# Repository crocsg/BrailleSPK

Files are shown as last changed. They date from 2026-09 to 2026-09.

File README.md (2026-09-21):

# BrailleSPK
 
 BrailleSPK is an experimental small device where you can enter a Braille character on a 6 dots permanent keyboard and use action switches to start some action. At the moment, when you used the first action switch, BrailleSPK will announce on audio the meaning of the Braille combination entered on the 6 dots Braille keyboard. All dots and switch are designed to be tactile so you can easily feel if one dots is pressed or not on the Braille keyboard, and you can also feel a little 'click' when you use the action switch. The 6 dots matrix keyboard is designed in such a way you can clearly feel if the button is up or down, so you can easily feel the Braille combination with a finger. At the end, the device frame, Braille dots and tactile switch  are 3d printed parts.

 The device is based on a 6 dots Braille permanent keyboard, 3 action switches, a Seeed Studio  XIAO ESP32C3, an I2S audio amp and a speaker. 

*An image of a fully assembled BrailleSPK*

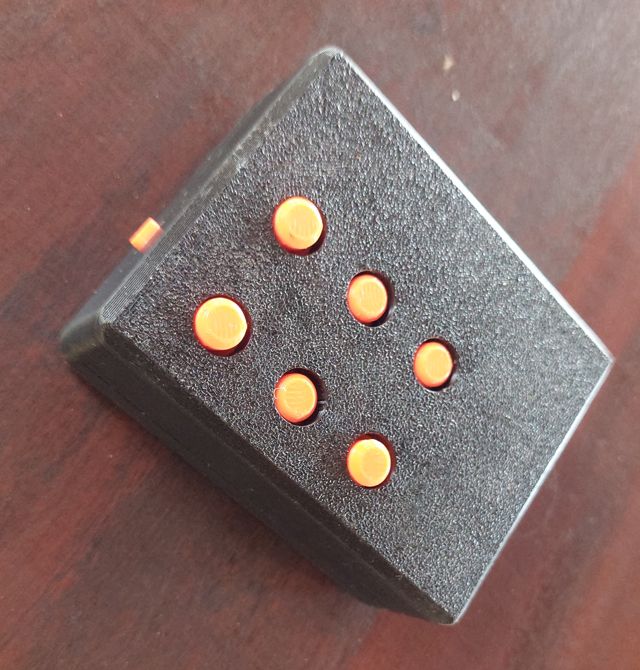
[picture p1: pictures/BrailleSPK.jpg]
An image of BrailleSPK device fully assembled with 6 large orange buttons for Braille, and a small orange tactile action switch


 ## Datasheet

 - a matrix keyboard with 2 columns and 4 rows. The Braille Keyboard use 2x3 switches position with lock/unlock switches. There is also 2 temporary switches on the 4th row we can use as temporary tactile switch.
 - 1 temporary switch connected to a GPIO, so it's suitable for interruption handling.
 - a Seeed Studio XIAO ESP32C3 (1 CPU, 4 Mo flash, 520 Mo RAM and Li-ION battery charge circuit)
 - an Adafruit MAX98357A I2S amplifier or compatible.
 - a 1510 cavitation speaker 

## BOM
  The Bill Of Material is available in [bom.md](bom.md)

## Building manual
  The assembly manual is available in [building.md](building.md)

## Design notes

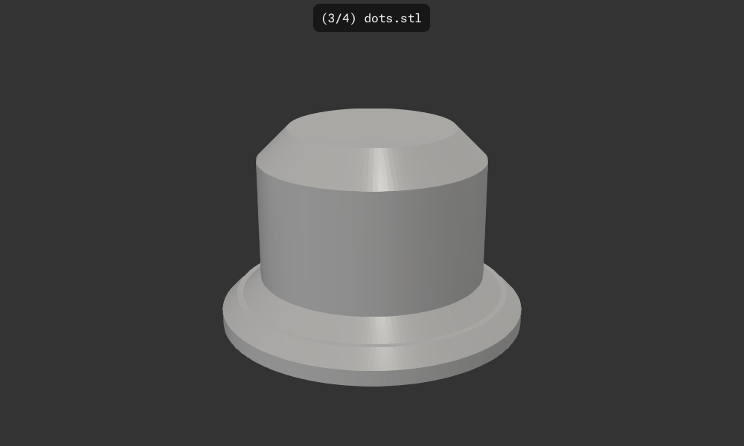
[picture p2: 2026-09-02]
pictures/dots_1.png

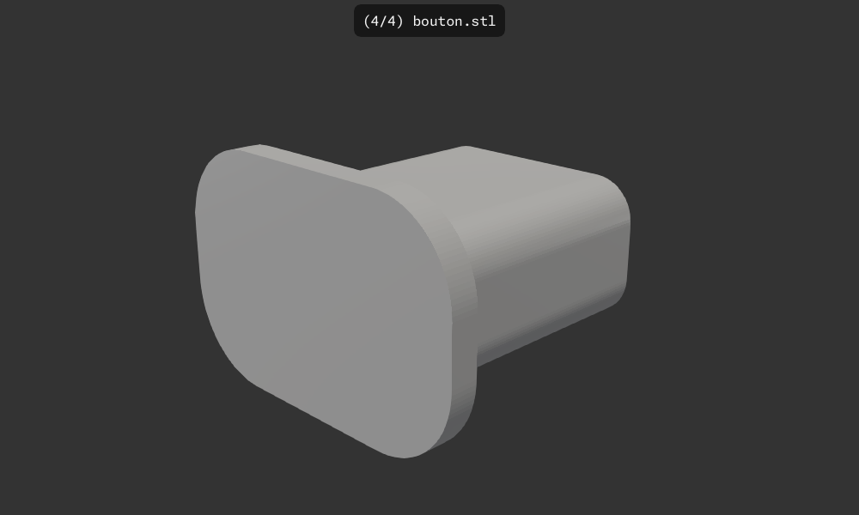
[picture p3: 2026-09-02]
pictures/bouton_1.png

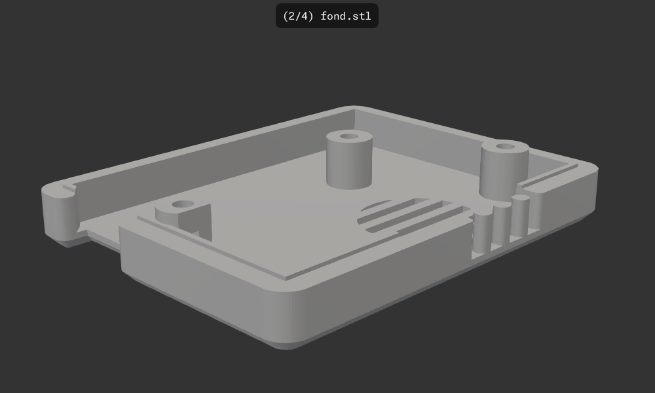
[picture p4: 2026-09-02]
pictures/fond_2.png

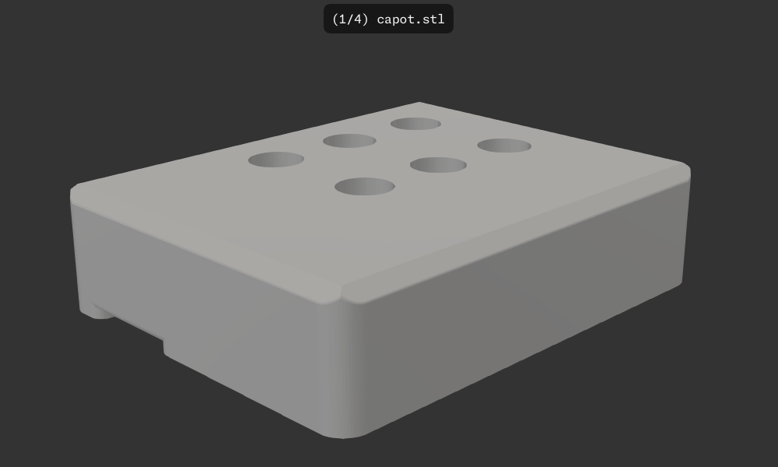
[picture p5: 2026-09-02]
pictures/capot_1.png

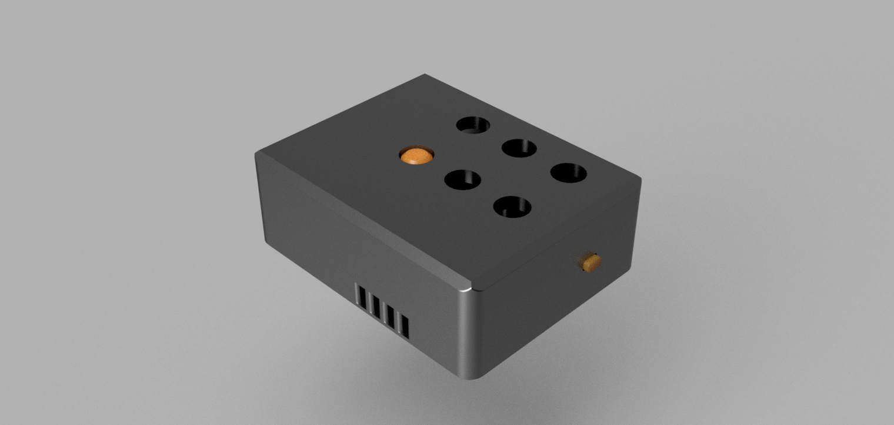
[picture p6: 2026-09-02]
pictures/BrailleSPKv2.png

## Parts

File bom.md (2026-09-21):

# BrailleSPK BOM

## 3D printed parts

 - 1 [capot.stl](3dprint\capot.stl) 
 - 1 [fond.stl](3dprint\fond.stl)
 - 1 [bouton.stl](3dprint\bouton.sl)
 - 6 [dots.stl](3dprint\dots.stl)

#### Printed parts details

  capot.stl
  Capot.stl

  fond.stl
  fond.stl

  bouton.stl
  bouton.stl

  dots.stl
  dots.stl

  These 3d views of printed part where generated with [F3D](https://f3d.app/) a great open source tool to display or render 3d files.

## Electronics

 - 1 BrailleSPK pcb (link coming soon)
 - 1 [Seeed Studio XIA ESP32-C3](https://wiki.seeedstudio.com/XIAO_ESP32C3_Getting_Started/).
 - 1 [Adafruit compatible I2S audio amp(MAX98357A)](https://www.adafruit.com/product/3006?srsltid=AU7gw4UqV06eJcSOT4ILpHE0YxdvCbpwST3pz8Ttz9znPxJfweLLO32w).
 - 1 [1510 Smartphone speaker](https://fr.aliexpress.com/item/1005009800665960.html).
 - 1 2.54 males headers pin (2 x 7pins for XIAO, 1 x 7pins for amp, 2 x 1pin for audio output).

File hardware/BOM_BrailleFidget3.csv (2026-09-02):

ID | Name | Designator | Footprint | Quantity | Manufacturer Part | Manufacturer | Supplier | Supplier Part | Price
1 | XIAO ESP32C3 | U9 | CONN-SMD_XIAO_ESP32C3 | 1 | XIAO ESP32C3 | null | LCSC | C19189385
2 | MAX98357A_KP | U7 | MAX98357A | 1 |  |  | ebay
3 | 1N4148WT_C970342 | D1,D2,D3,D4,D5,D6,D7,D8 | SOD-523F_L1.2-W0.8-LS1.7-RD | 8 | 1N4148WT | LGE(鲁光) | LCSC | C970342 | 0.013
4 | HDR-M-2.54_1x2 | J1 | HDR-M-2.54_1X2 | 1 |  |  | LCSC | C124375 | 0.03
5 | TS24CA 250GF 013 | SW1,SW2,SW3 | SW-SMD_L4.7-W3.5-P3.35-EH | 3 | TS24CA 250gf 013 | SHOU HAN(首韩) | LCSC | C5373430 | 0.026
6 | PS-7054DVB-6PL-REG | U1,U2,U3,U4,U5,U6 | SW-TH_6P-L7.0-W7.0-P2.00-REG. | 6 | PS-7054DVB-6PL | G-Switch(品赞) | LCSC | C22363819 | 0.176
7 | 100kΩ | U8 | R0402 | 1 | FRC0402J104 TS | FOJAN(富捷) | LCSC | C2906883 | 0.002

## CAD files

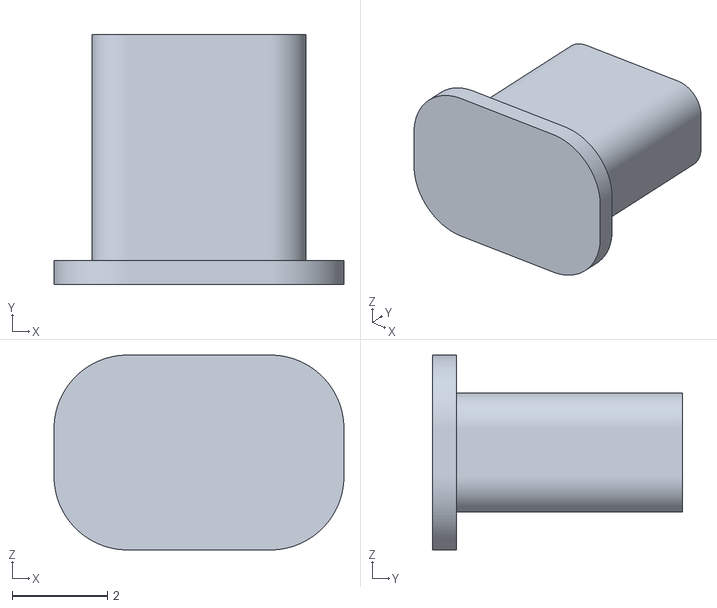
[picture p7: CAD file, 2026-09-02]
3dprint/bouton.stl
6.10 x 5.25 x 4.10

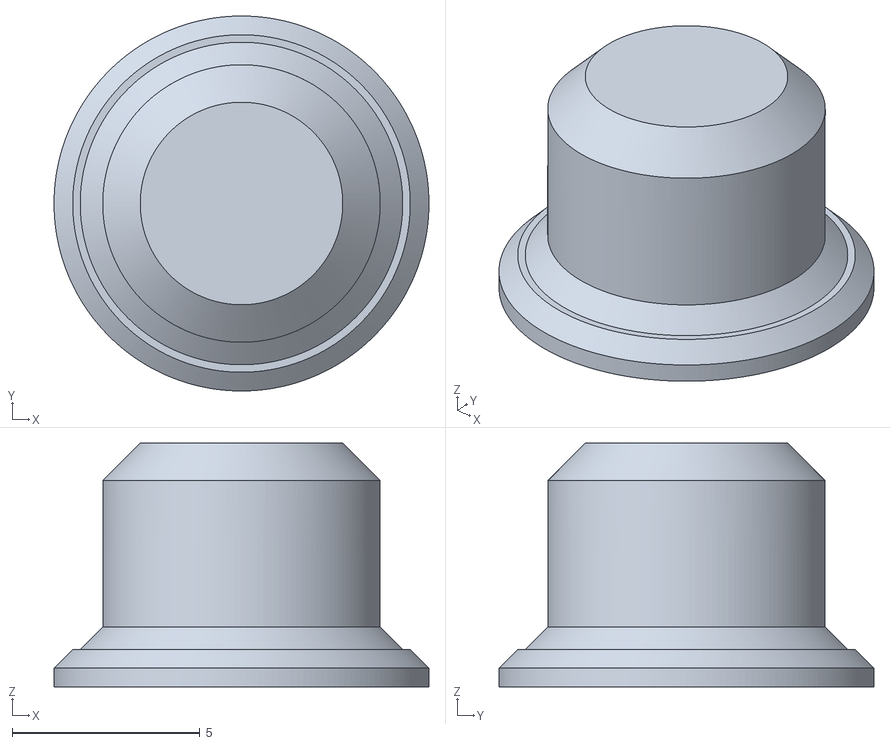
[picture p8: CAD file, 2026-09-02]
3dprint/dots.stl
10.0 x 10.00 x 6.50

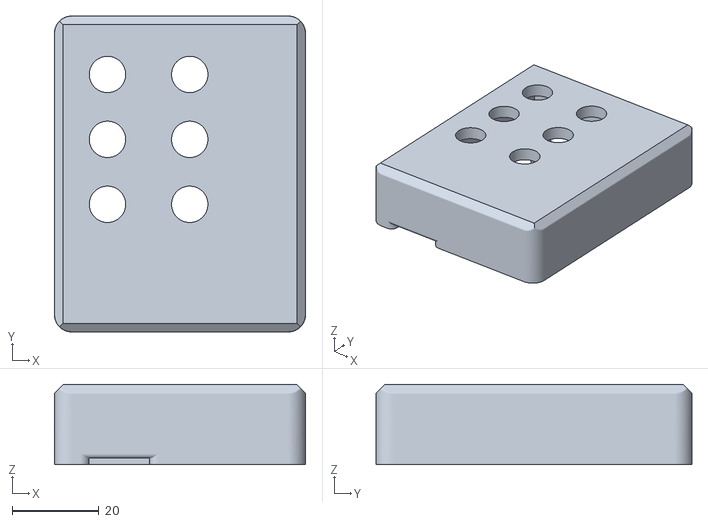
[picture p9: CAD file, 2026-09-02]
3dprint/capot.stl
58.0 x 73.0 x 18.5

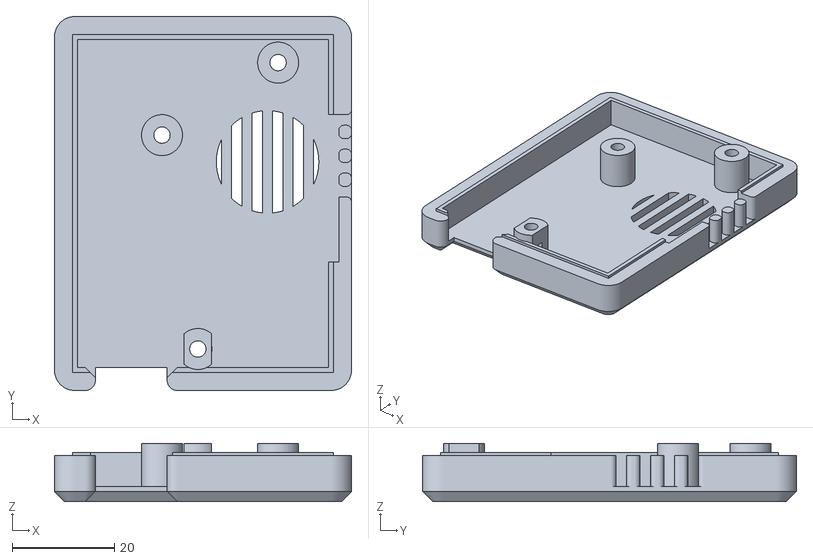
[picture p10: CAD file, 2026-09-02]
3dprint/fond.stl
58.0 x 73.0 x 11.4

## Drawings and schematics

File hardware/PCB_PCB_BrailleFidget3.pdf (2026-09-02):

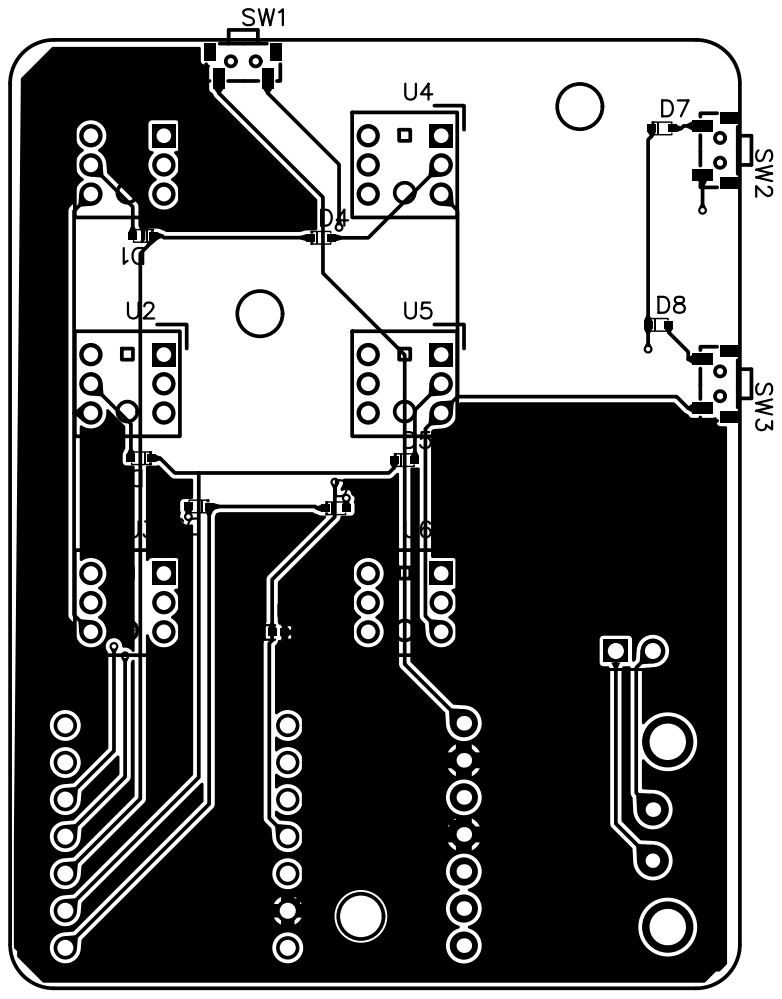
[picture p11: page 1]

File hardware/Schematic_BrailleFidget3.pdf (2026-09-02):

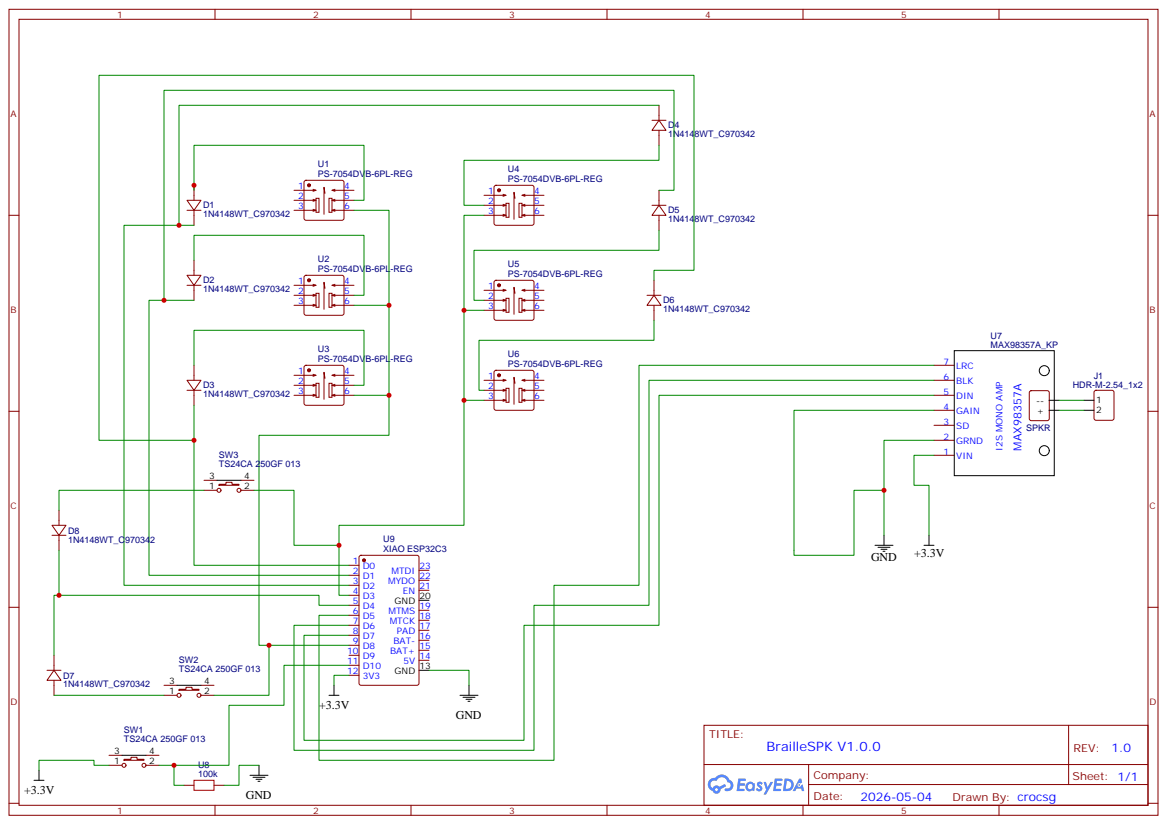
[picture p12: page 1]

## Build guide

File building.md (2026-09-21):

# BrailleSPK building manual

## Solder elements on PCB

### XIAO ESP32-C3 Welding

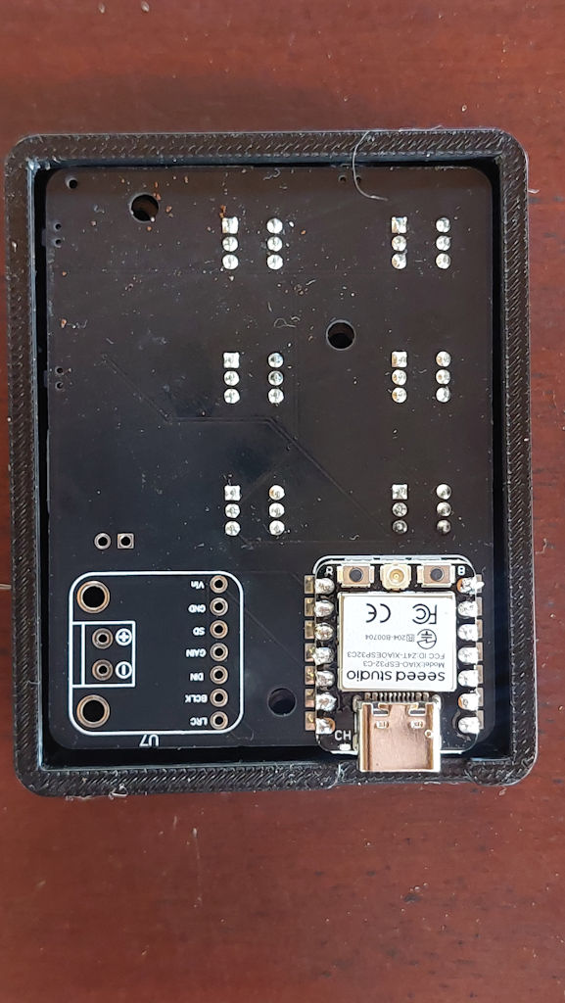
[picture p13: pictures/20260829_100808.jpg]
The ESP32C3 in place


 - Take care of the USB connector orientation to place the MCU on board

### Audio Amp Welding

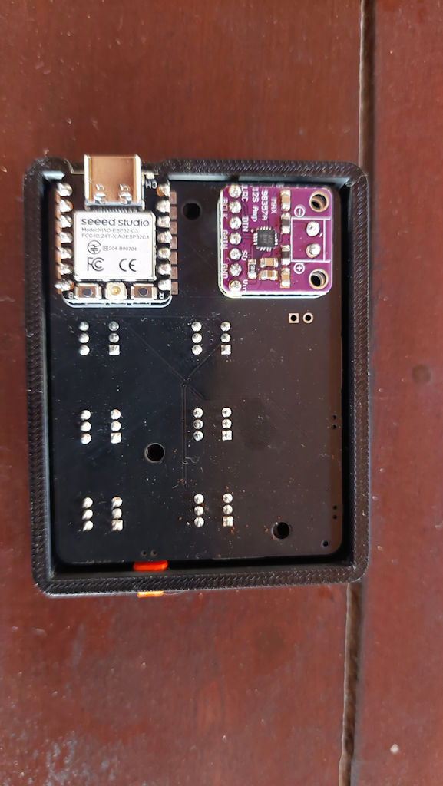
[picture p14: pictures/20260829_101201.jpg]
The audio amp in place


 - We use header pin to solder the audio output on the PCB. On audio amp the output connector use 3mm space. I've used 2 isolated pins cut from a standard 2.54 header.

### Soldering the speaker and glue it on PCB

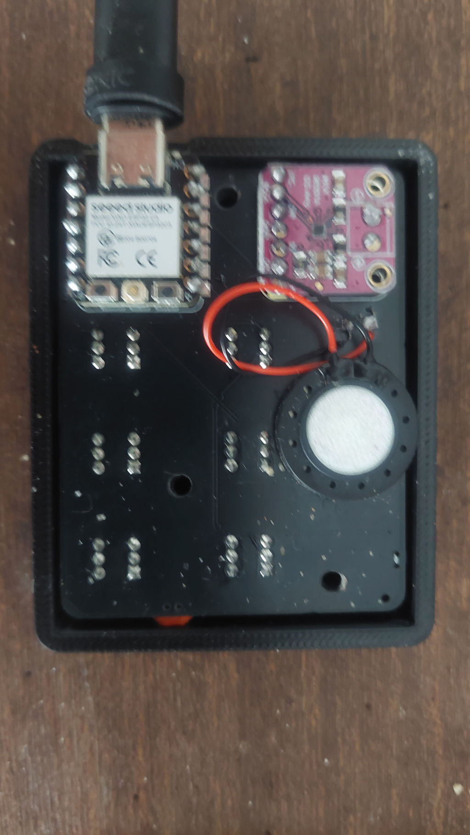
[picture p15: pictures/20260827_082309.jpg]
The audio speaker in place


- Solder the speaker wire on the BrailleSPK PCB. Respect the +/- polarity of the speaker.
- Glue the speaker on the PCB. Most 1510 speaker are equipped with adhesive tape.

### Upload the firmware

 - Open the firmware in 'firmware' directory with Arduino IDE version 2.3.x or later
 - Install ESP32 compiler if needed ([detail instructions available here](https://wiki.seeedstudio.com/Getting_Started_with_Arduino/))
 - Select **XIAO ESP32-C3** in menu **Tools/Board**.

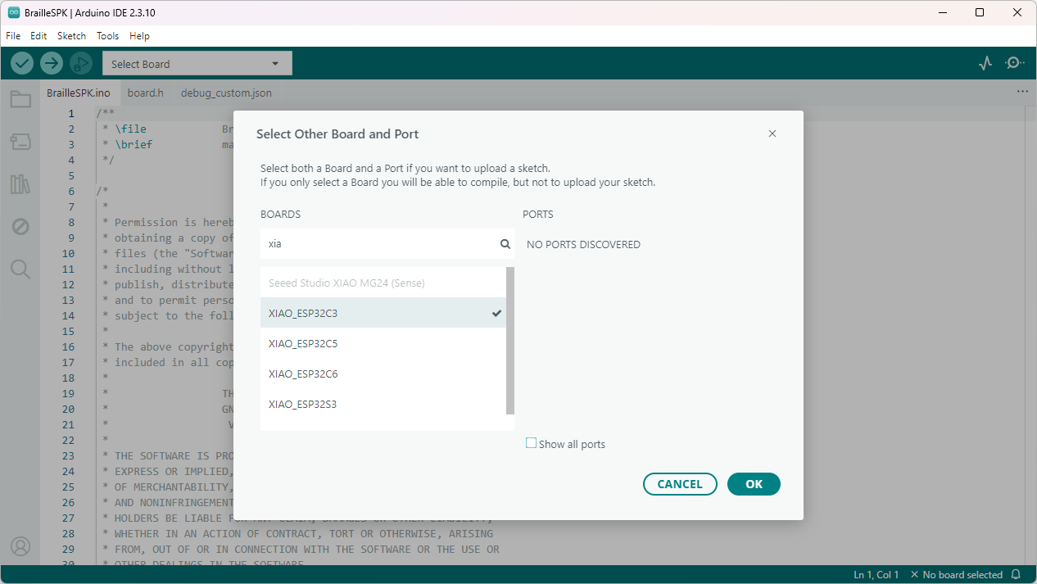
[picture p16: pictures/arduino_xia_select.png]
Select XIAO
 
 
 - Select "Huge partition scheme" in menu **Tools/Partition Scheme**.

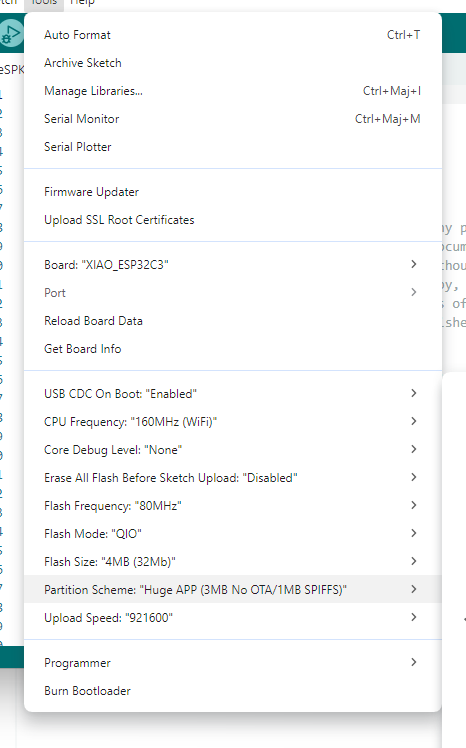
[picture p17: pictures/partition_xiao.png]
Huge partition scheme
 

 - Compile and upload the firmware

### Install Braille dots on BrailleSPK PCB

 - Gently insert 6 dots.stl on each keyboard switch of the BrailleSPK PCB.

### Install the action button

  - Insert the **bouton.stl** part in the hole on the top of the part **capot.stl**.

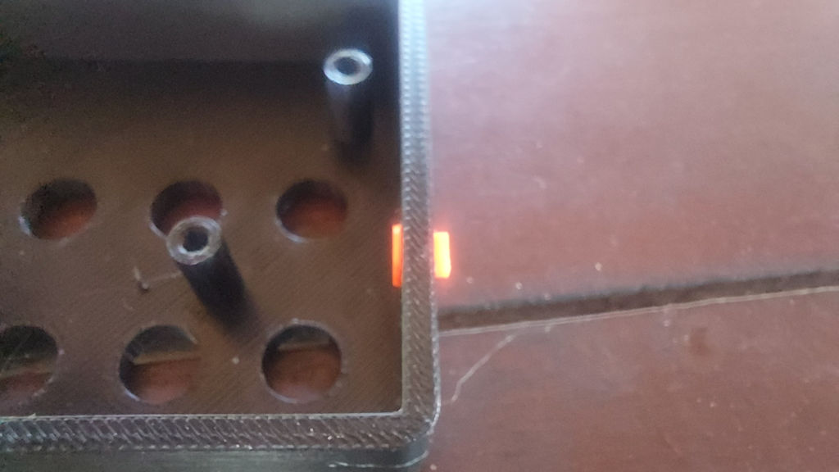
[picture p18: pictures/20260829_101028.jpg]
   

### Install the PCB

 - Gently put the PCB in place in **capot.stl** part, take care the action bouton stay in place.

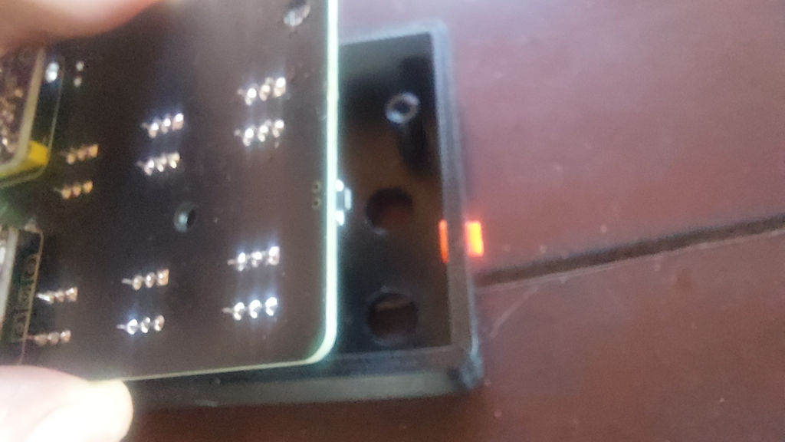
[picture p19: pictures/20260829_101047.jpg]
Place the PCB
 

 - Check that the action button is aligned with the PCB switch.

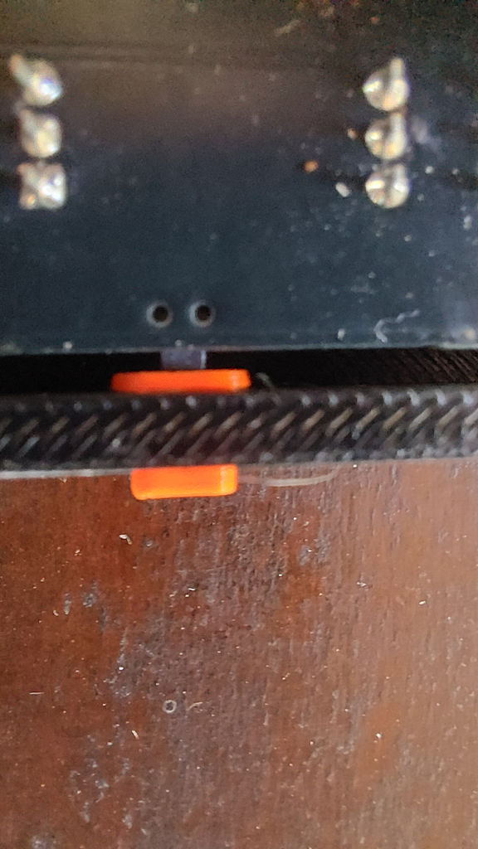
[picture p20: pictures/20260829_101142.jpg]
 

### Close the box

 - Put in place the part **fond.stl**. Use 3 M3-12 hex screw to secure the assembly.

## Enjoy !

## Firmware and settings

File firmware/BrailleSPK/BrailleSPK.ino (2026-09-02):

/**
 * \file            BrailleSPK.ino
 * \brief           main control loop
 */

/*
 *
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
 *                  THE SOFTWARE IS LICENSED UNDER
 *                  GNU GENERAL PUBLIC LICENSE
 *                   Version 3, 29 June 2007
 * 
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
 * This file is part of BrailleSPK software.
 *
 * SPDX-FileCopyrightText: 2026 Stephane GODIN <stephane@braillerap.org>
 * 
 * SPDX-License-Identifier: GPL-3.0 
 */



#include "AudioTools.h"   // https://github.com/pschatzmann/arduino-audio-tools
#include "espeak.h"       // https://github.com/pschatzmann/arduino-espeak-ng
                          // https://github.com/pschatzmann/arduino-posix-fs
#include "board.h"

#define DEFAULT_VOLUME 120  // default Brialle combination volume level
#define START_VOLUME 120    // Volume level for announcement at start

#define DEFAULT_RATE 95     // Braille combination annouement speed rate
#define START_RATE 80       // speed rate for announcement at start


// TTS init
I2SStream i2s;
ESpeak espeak(i2s, false);



void setup() 
{

  // kerboard matrix init
  pinMode (COL1, OUTPUT);
  pinMode (COL2, OUTPUT);
  pinMode (ROW1, INPUT_PULLDOWN);
  pinMode (ROW2, INPUT_PULLDOWN);
  pinMode (ROW3, INPUT_PULLDOWN);
  pinMode (BTNROW, INPUT_PULLDOWN);
  pinMode (PIN_BTN, INPUT);

  // Serial debug configuration
  //Serial.begin(115200);
  
  //digitalWrite(LED_PIN, HIGH);

  //while(!Serial);
  //AudioLogger::instance().begin(Serial, AudioLogger::Info);

  ////espeak.add("/mem/data/fr_dict", espeak_ng_data_fr_dict, espeak_ng_data_fr_dict_len);
  ////espeak.add("/mem/data/lang/fr", espeak_ng_data_lang_roa_fr, espeak_ng_data_lang_roa_fr_len);
  //espeak.add("/mem/data/voices/!v/whisper", espeak_ng_data_voices__v_whisper, espeak_ng_data_voices__v_whisper_len);
  ////espeak.add("/mem/data/voices/!v/norbert", espeak_ng_data_voices__v_norbert, espeak_ng_data_voices__v_norbert_len);
  //espeak.add("/mem/data/voices/!v/steph", espeak_ng_data_voices__v_steph, espeak_ng_data_voices__v_steph_len);
  //espeak.add("/mem/data/voices/!v/Annie", espeak_ng_data_voices__v_Annie, espeak_ng_data_voices__v_Annie_len);
  //espeak.add("/mem/data/voices/!v/mb-fr6", espeak_ng_data_voices_mb_mb_fr6, espeak_ng_data_voices_mb_mb_fr6_len);
  //espeak.add("/mem/data/voices/!v/mb-fr2", espeak_ng_data_voices_mb_mb_fr2, espeak_ng_data_voices_mb_mb_fr2_len);
  //espeak.add("/mem/data/voices/!v/mb-fr2", espeak_ng_data_voices_mb_mb_fr2, espeak_ng_data_voices_mb_mb_fr2_len);
  //espeak.add("/mem/data/voices/mb/mb-fr2", espeak_ng_data_voices_mb_mb_fr2, espeak_ng_data_voices_mb_mb_fr2_len);
    //espeak.add("/mem/data/voices/!v/mb-fr2", espeak_ng_data_voices_mb_mb_fr2, espeak_ng_data_voices_mb_mb_fr2_len);

#if 1
  espeak.add("/mem/data/en_dict", espeak_ng_data_en_dict, espeak_ng_data_en_dict_len);
  espeak.add("/mem/data/lang/en", espeak_ng_data_lang_gmw_en_US, espeak_ng_data_lang_gmw_en_US_len);
  espeak.add("/mem/data/voices/mb/mb-de1-en", espeak_ng_data_voices_mb_mb_de1_en, espeak_ng_data_voices_mb_mb_de1_en_len);
 //espeak.add("/mem/data/voices/!v/Alicia", espeak_ng_data_voices__v_Alicia, espeak_ng_data_voices__v_Alicia_len);

  // start TTS
  espeak.begin();
  
  // Select a voice suitable for EN language
  espeak.setVoice("en+en-german-1");

  // start I2S hardware
  audio_info espeak_info = espeak.audioInfo();
  auto cfg = i2s.defaultConfig();                     //  CF lib : audio-tools/src/AudioConfig.h
  cfg.channels = espeak_info.channels;                // 1
  cfg.sample_rate = espeak_info.sample_rate;          // 22050
  cfg.bits_per_sample = espeak_info.bits_per_sample;  // 16
  cfg.pin_ws    = PIN_LCBRK;                             //12; // lrck
  cfg.pin_bck   = PIN_BCLK;                             //14; // bclk
  cfg.pin_data  = PIN_DOUT;                            //27; // dout cote esp
  cfg.pin_data_rx = -1;                               // din cote esp
  i2s.begin(cfg);

  // say hello at start
  espeak.setVolume(START_VOLUME); 
  espeak.setRate (START_RATE);

  espeak.say("Hello !");
  espeak.say("You know what ?");
  espeak.say("I'm happy");

#endif
  delay(250);

  // set volume and speed rate to Braille announcement level
  espeak.setVolume(DEFAULT_VOLUME); 
  espeak.setRate (DEFAULT_RATE);
  
}

// Nato letter code
static const char* nato[] = {
    "Alfa",
    "Bravo",
    "Charlie",
    "Delta",
    "Echo",
    "Foxtrot",
    "Golf",
    "Hotel",
    "India",
    "Juliet",
    "Kilo",
    "Lima",
    "Mike",
    "November",
    "Oscar",
    "Papa",
    "Quebec",
    "Romeo",
    "Sierra",
    "Tango",
    "Uniform",
    "Victor",
    "Whiskey",
    "X-ray",
    "Yankee",
    "Zulu"
};

static uint8_t d1, d2, d3, d4, d5, d6,btn, btn1, btn2;
static uint8_t braille = 0;
static uint8_t code_found = 0;

// func: keyboard_read
//
// desc: Use keyboard matrix to read buttons states
// Braille dot are stored in d1->d6
// Side buttons are stored in btn1 and btn2
//

void keyboard_read ()
{
  // select column 1
  digitalWrite(COL1, HIGH);
  digitalWrite(COL2, LOW);
  delay (1);
  // read buttons state
  d1 = (uint8_t) (digitalRead (ROW1) ? 0 : 1);
  d2 = (uint8_t) (digitalRead (ROW2) ? 0 : 1);
  d3 = (uint8_t) (digitalRead (ROW3) ? 0 : 1);
  btn1 = (uint8_t) digitalRead (BTNROW);

  // select column 2
  digitalWrite(COL1, LOW);
  digitalWrite(COL2, HIGH);
  delay (1);
  // read buttons state
  d4 = (uint8_t) (digitalRead (ROW1) ? 0 : 1);
  d5 = (uint8_t) (digitalRead (ROW2) ? 0 : 1);
  d6 = (uint8_t) (digitalRead (ROW3) ? 0 : 1);
  btn2 = (uint8_t) digitalRead (BTNROW);

  // build Braille dots combination
  braille = d1 | (d2 << 1) | (d3 << 2) | (d4 << 3) | (d5 << 4) | (d6 << 5);
}


// basic english Braille code (UEB)
static uint8_t brcode[]= {
  0x01, // a
  0x03, // b
  0x09, // c
  0x19, // d
  0x11, // e
  0x0b, // f
  0x1b, // g
  0x13, // h
  0x0a, // i
  0x1a, // j
  0x05, // k
  0x07, // l
  0x0d, // m
  0x1d, // n
  0x15, // o
  0x0f, // p
  0x1f, // q
  0x17, // r
  0x0e, // s
  0x1e, // t
  0x25, // u
  0x27, // v
  0x3a, // w
  0x2d, // x
  0x3d, // y
  0x35, // z

};

// basic UEB escape sequence in Braille
static uint8_t brescape[] = {
  0x3c, // number indicator
  0x32, // period
  0x16,
  0x02, // comma
  0x04, // apostrophe
  0x12, // colon
  0x06, // a semi colon
  0x26, // opening quotation mark
  0x34,
  0x24, // hyphen
  0x0c, // fraction line
  0x20
};

// Latin letter associated with Braille code 
const char* datastr = "abcdefghijklmnopqrstuvwxyz";

// Escape description associated with Braille code
const char* escapestr[] = {
  "Number indicator",
  "A period or a decimal separator",
  "Exclamation point",
  "A comma",
  "An apostrophe",
  "A colon",
  "A semi colon",
  "Opening quotation mark",
  "Closing quotation mark",
  "Hyphen",
  "Fraction line",
  "Capital"

};

void loop ()
{
  
  // read main button state
  btn = (uint8_t) digitalRead (PIN_BTN);

  if (btn)
  {
    char sentence[256]; 

    // read keyboard
    keyboard_read ();

    // print keyboard state on debug console
    Serial.printf ("%02x | %02x %02x %02x %02x %02x %02x | %02x, %02x |%02x \r\n", btn, d1, d2, d3, d4, d5, d6, btn1, btn2, braille);
    
    code_found = 0;

    // search Braille code
    for (uint8_t i = 0; i < sizeof(brcode); i++)
    {
      if (braille == brcode[i])
      {
        code_found = 1;
        {
          // build a sentence with latin letter associated with Braille
          sprintf (sentence, "%c   ", datastr[i]);
          Serial.printf (sentence);

          // announce the letter via TTS
          espeak.say(sentence);
          
          // Pause a little bit
          delay(200);

          // build a sentence with Nato letter name
          sprintf (sentence, "as in %s", nato[i]);
          Serial.printf (sentence);

          // use TTS to anounce Nato code
          espeak.say(sentence);
          delay(25); 
          break;
        }
      }
    }
    if (code_found == 0)
    {
      // search Braille escape description
      for (uint8_t i = 0; i < sizeof(brescape); i++)
      if (braille == brescape[i])
      {
        Serial.printf (escapestr[i]);

        // use TTS to speak Braille escape description
        espeak.say(escapestr[i]);
        delay(25);
        break;
      }
    }
  }
}

void loopb()
{
  
  
  //digitalWrite(PIN_GAIN, _volume[pitch][1] ? HIGH : LOW);     // gain ampli
  //digitalWrite(LED_PIN, _volume[pitch][1] ? HIGH : LOW);     // gain ampli

  //Serial.printf ("pitch=%d volume=%d gain=%d\r\n",pitch, _volume[pitch][0],_volume[pitch][1] );

  espeak.say("Hello the world.");
  delay(500);
  espeak.say("I'm happy.");
  delay(500);
  const char* datastr = "abcdefghijklmnopqrstuvwxyz";
  char sentence[256]; 
  for (int i = 0; i < strlen(datastr); i++)
  {
    sprintf (sentence, "%c   as in %s", datastr[i], nato[i]);
    espeak.say(sentence);
    delay(1000);
  }
  

  

 
  
   
}

static uint8_t _led = 0;




void loop2 ()
{
  digitalWrite(COL2, LOW);
  digitalWrite(COL1, HIGH);
  delay (1);
  d1 = (uint8_t) digitalRead (ROW1);
  d2 = (uint8_t) digitalRead (ROW2);
  d3 = (uint8_t) digitalRead (ROW3);
  btn1 = (uint8_t) digitalRead (BTNROW);

  digitalWrite(COL1, LOW);
  digitalWrite(COL2, HIGH);
  delay (1);
  d4 = (uint8_t) digitalRead (ROW1);
  d5 = (uint8_t) digitalRead (ROW2);
  d6 = (uint8_t) digitalRead (ROW3);
  btn2 = (uint8_t) digitalRead (BTNROW);

  btn = (uint8_t) digitalRead (PIN_BTN);

  Serial.printf ("%02x | %02x %02x %02x %02x %02x %02x | %02x, %02x \r\n", btn, d1, d2, d3, d4, d5, d6, btn1, btn2);

}

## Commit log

2026-09-02 feat: add production files / firmware / images
    [BOM_BrailleFidget3.csv, PickAndPlace_PCB_BrailleFidget3.csv, bouton.stl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]
2026-09-21 doc: add building instructions and bom
2026-09-21 doc: add bom and building instruction link
